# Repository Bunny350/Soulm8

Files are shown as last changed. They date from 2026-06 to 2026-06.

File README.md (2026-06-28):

# Soulm8 for [redacted] and Voron Trident
**"There is no Oitswilliam-made machine with no gimmicks."**
Soulm8 printer status indicator for [redacted] and Voron Trident.

It is just pronounced "soulmate", if you don't understand what Soulm8 is, say it, or refer to "m8".

## Features
Soulm8 is a printer status indicator made initially for Oitswilliam's upcoming 3D printer design that is based of Voron Trident with FrankenVoron Tridex, but because of the keyword *based of Voron Trident*, it is also compatible with Voron Trident.

### Status
Soulm8 uses pulsing indications for status. Note that when the status is off, then it is idle.
* None - idle or power off
* Amber yellow, blinking quickly and delay - printing
* Orange, blinking - paused, attention needed

## Bill-of-materials
* 2cm Neopixel RGB strip (100pc/m)
* M3x16mm FHCS countersunk, BHCS or SHCS
* The cables (2464 26AWG recommended), see wire requirement section on how to cut to length.

## Hardware and software requirements
### Hardware
The printer must be Voron Trident or similar that uses 2020 extrusion, support for 1515 and other 3D printers with stationary gantry are considered.

Mounting on other forms (i.e. Voron 2) work, but is not optimized.

### Software
Because we are lazy and we don't need to be primitive since we can install [Klipper LED effect add-on by Julian Schill](https://github.com/julianschill/klipper-led_effect) that I've used almost five years ago since V2.3347, Soulm8 is easy to install.

Be noted that the Soulm8 LED status require such add-on.

## Wire requirement
The cable is recommended to be shielded, 2- to 3-wire and the wire must be at least 26AWG.
* Shield connects to ground,
* Red connecs to 5V,
* Unless if only containing 2-wire, anything else connects to data pin.
### Cable length guide
* (X distance / 2) + 10mm + Y distance + (Z distance * 1.5) + 40mm + (Y distance * .8) = raw wire length ≈ rounded-off cable length in mm
* For example, if XYZ distances are all 250, then the value is (250 / 2) + 10 + 250 + (250 * 1.5) + 40 + (250 * .8) = 1000 and the Soulm8 cable length is that, 1000mm.

## Hardware installation
1. Feed the wire to the third cutout (second square, slightly smaller square) of soulm8_trident_shell.stl.
2. Remove the insulation at around 2cm of length.
3. Cut the LED strip to around 2cm, if using LED strip.
4. Attach the LED strip to soulm8_trident_indicator_unit.stl
5. Assemble the unit. Place soulm8_trident_indicator_unit.stl to soulm8_trident_shell.stl, and then secure them with soulm8_trident_wire_cover.stl.
6. Install Soulm8 hardware to the printer. The wire must face right (if the screw is on left) or installation will be conflicted on itself.
7. Feed the connector end of Soulm8 LED cable to the top-center of the bed (if it is), then to the bed cable chain, and then below deck.
8. Connect Soulm8 LED cable to the MCU with a free signal, 5V and ground pin.
9. Organize Soulm8 LED cable and attach several (at least 3, one front-left, and two center-right) soulm8_cable_organizer_piece.stl to the extrusion. 

## Macro modifications
Manual implementation is needed for Soulm8 to function. Soulm8 is made-optimized for [Non-motion MCU](https://github.com/Bunny350/Non-motion-MCU) but the pin can be changed to your decision. Check out soulm8.cfg for exact software installation.

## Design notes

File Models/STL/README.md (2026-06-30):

# Soulm8 printable models
This folder contains materials for the printable Soulm8 models.
## Printing guide
### soulm8_trident_indicator_unit.stl
* Transparent PETG or PC
* 1.6mm walls (4 wall count if 0.4mm)
* 100% infill density
* No supports required
* May be printed slower and 1% to 3% more flow than preset. You may [check out the article by Rygar1432 on Printables for the exact guide](https://www.printables.com/model/15310-how-to-print-glass).
    * Some materials are not truly transparent.
### Rest of the models
* Base color of the printer, ABS, ASA or PETG.
* 1.6mm walls (4 wall count if 0.4mm) 
* 40% infill density
* No supports required

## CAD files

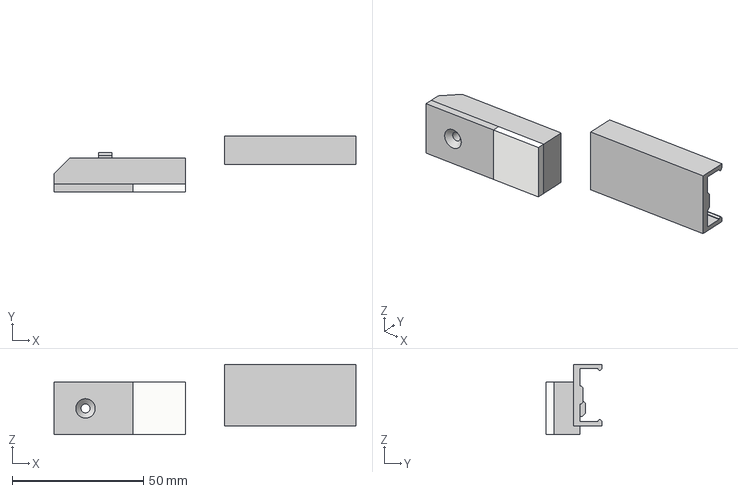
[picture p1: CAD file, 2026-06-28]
Models/CAD/soulm8_trident.step
115.0 x 21.4 x 26.8 mm

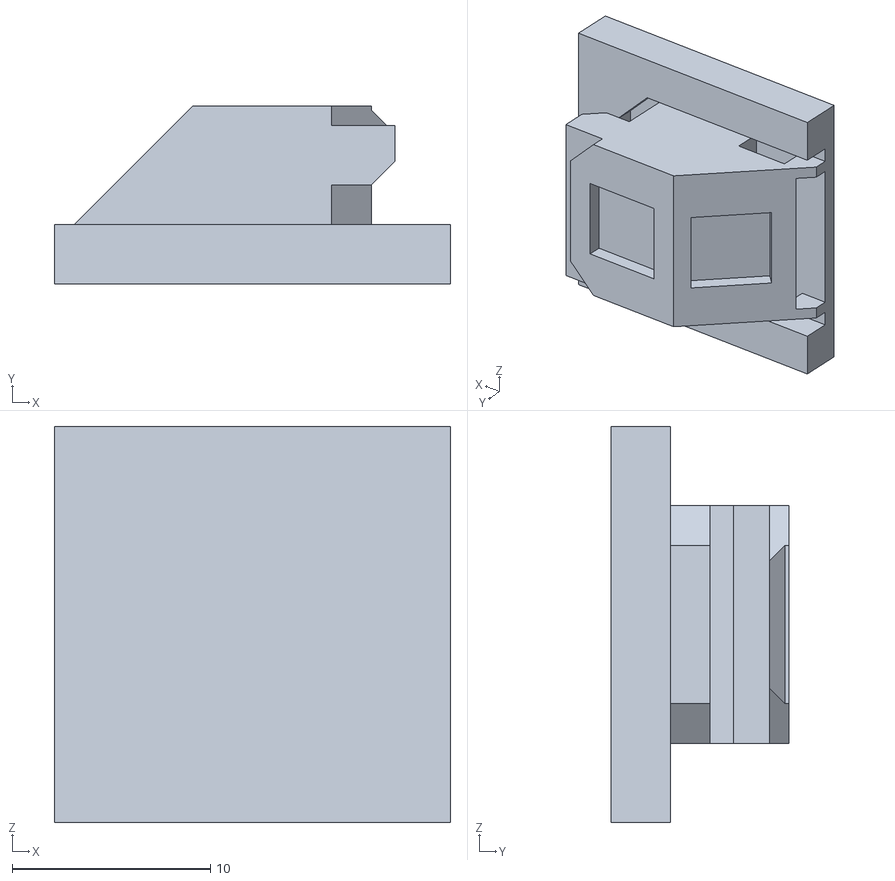
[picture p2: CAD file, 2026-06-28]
Models/STL/soulm8_trident_indicator_unit.stl
20.0 x 9.00 x 20.0

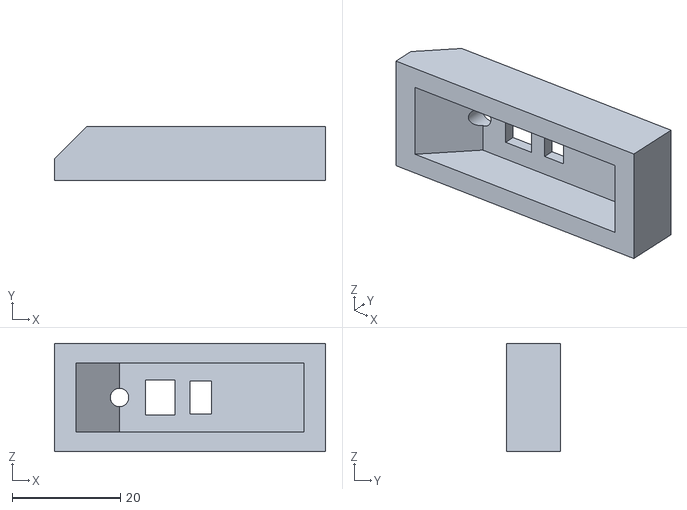
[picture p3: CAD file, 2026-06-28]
Models/STL/soulm8_trident_shell.stl
50.0 x 10.0 x 20.0

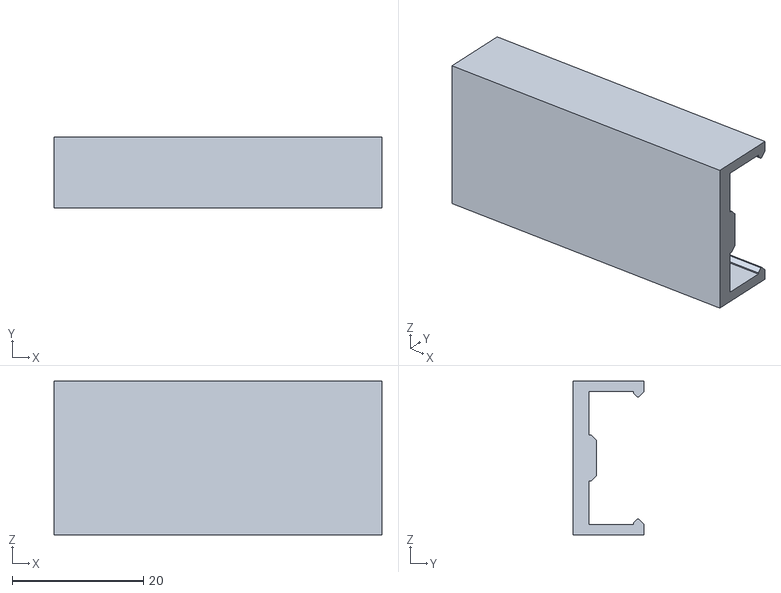
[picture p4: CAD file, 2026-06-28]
Models/STL/soulm8_cable_organizer_piece.stl
50.0 x 10.8 x 23.4

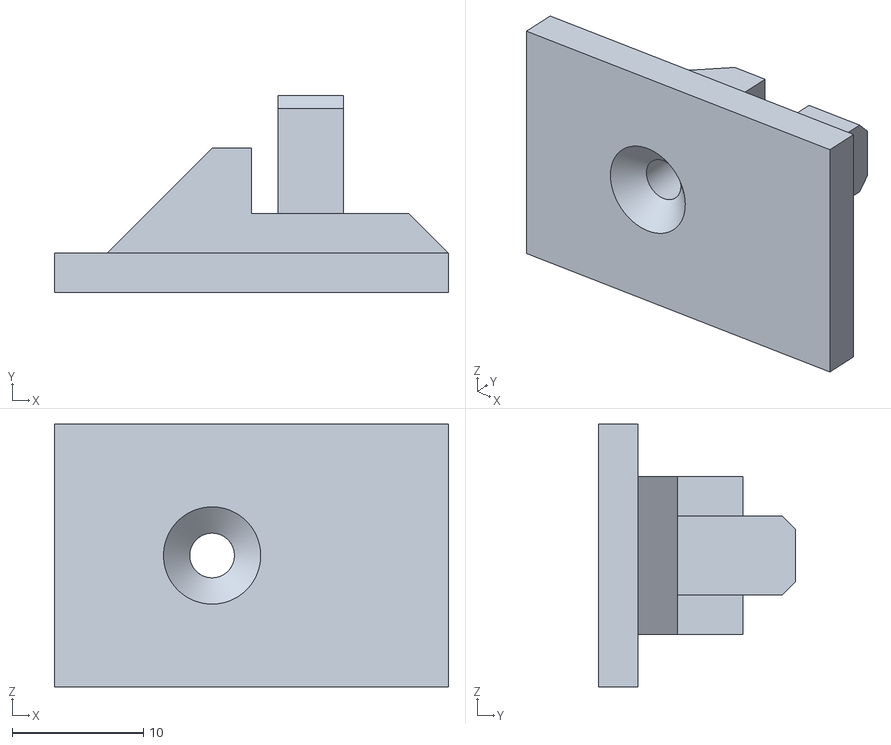
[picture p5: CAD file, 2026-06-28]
Models/STL/soulm8_trident_wire_cover.stl
30.0 x 15.0 x 20.0

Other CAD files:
Models/CAD/soulm8_trident.f3d

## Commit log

2026-06-28 Early access release
    This update introduces Soulm8 for [redacted] and Voron Trident for everyone to test and torture.
    [soulm8.cfg, soulm8_cable_organizer_piece.stl, soulm8_trident.f3d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]
2026-06-30 Create README.md
    Add printing guide for such project.
